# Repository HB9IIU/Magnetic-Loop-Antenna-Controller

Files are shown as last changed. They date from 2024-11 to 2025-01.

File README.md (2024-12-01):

# Magnetic Loop Antenna Auto-Tuner

## Introduction

I have always been fascinated by Magnetic Loop Antennas. While I’m not a fanatical radio ham (I only go on air occasionally and for short periods—I'm not really into contests but rather enjoy technical discussions, which are becoming increasingly rare), what truly captivates me is the challenge of tuning these antennas, especially due to their very high Q factor.

For those not familiar with the term, "high Q" refers to the quality of the antenna's resonance. A high-Q antenna means it has a very narrow bandwidth, which makes it more sensitive to small changes in frequency. This requires precise tuning, which is both challenging and rewarding. The higher the Q, the more critical it is to fine-tune the antenna for optimal performance.

---

## Project Overview
This project is a fully automated tuning system for a Magnetic Loop Antenna (MLA), designed to simplify and enhance the tuning experience, especially for high-Q antennas. The setup consists of a **Master** ESP32 microcontroller that serves as the main controller, paired with a **Slave** ESP32 that manages the motor controlling the antenna's tuning capacitor.
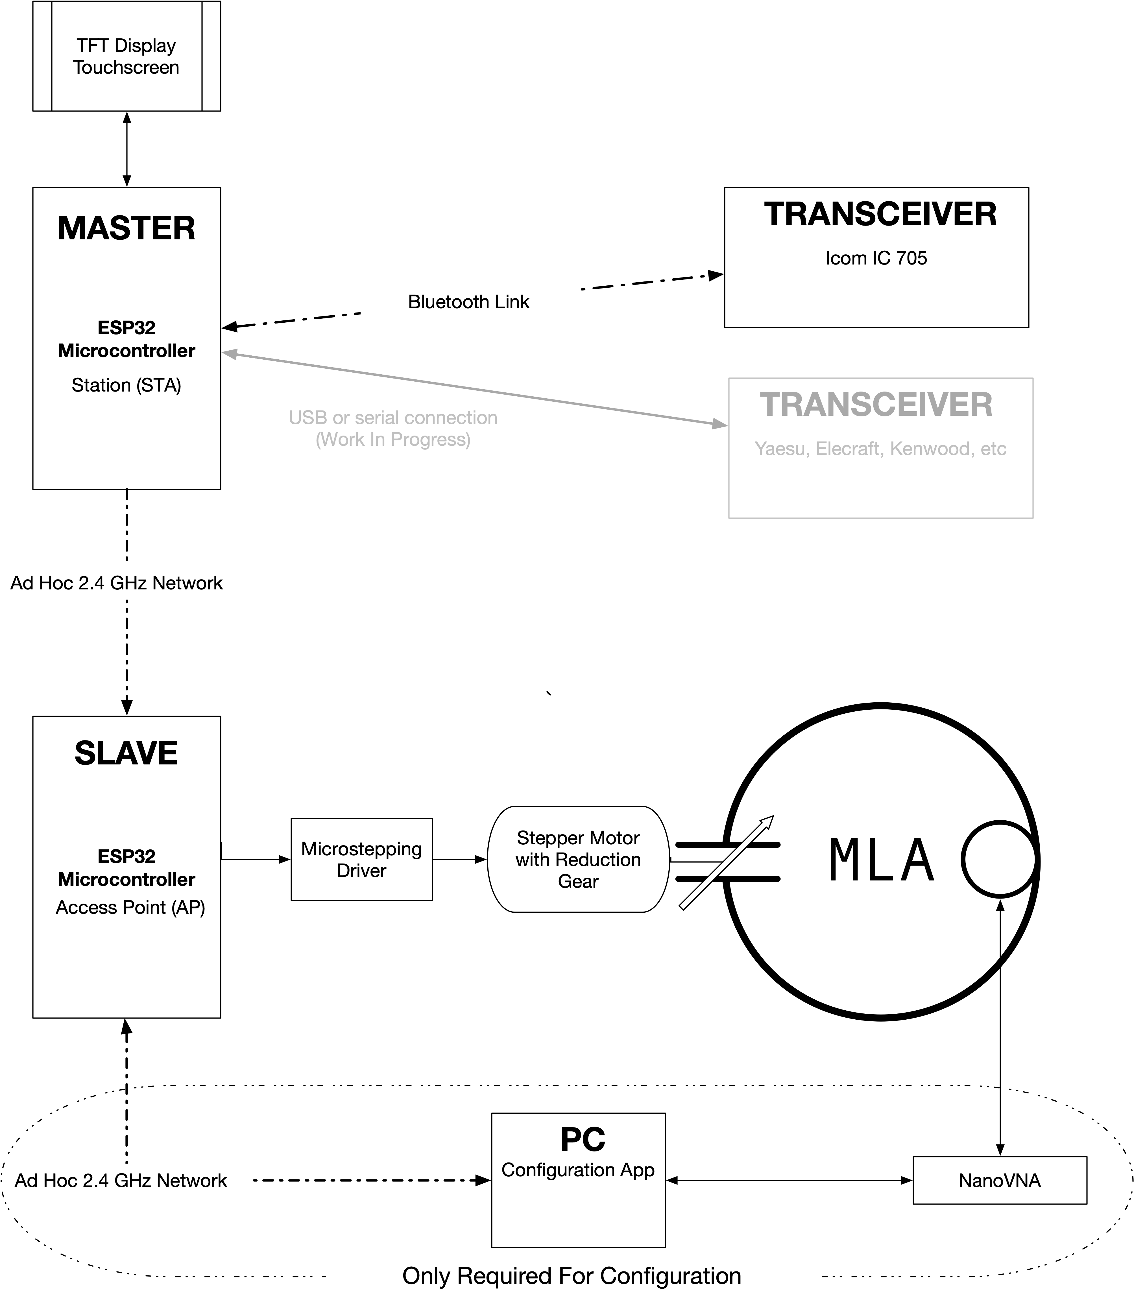
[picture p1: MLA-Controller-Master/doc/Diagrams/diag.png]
MLA Controller Image


<div style="text-align: center;">
    <a href="https://www.youtube.com/watch?v=2oa5XWuVh9o" target="_blank">
        Short Demo
    </a>
</div>

[Right-click here and open in a new tab to watch the video](https://www.youtube.com/watch?v=2oa5XWuVh9o)
<p float="left">
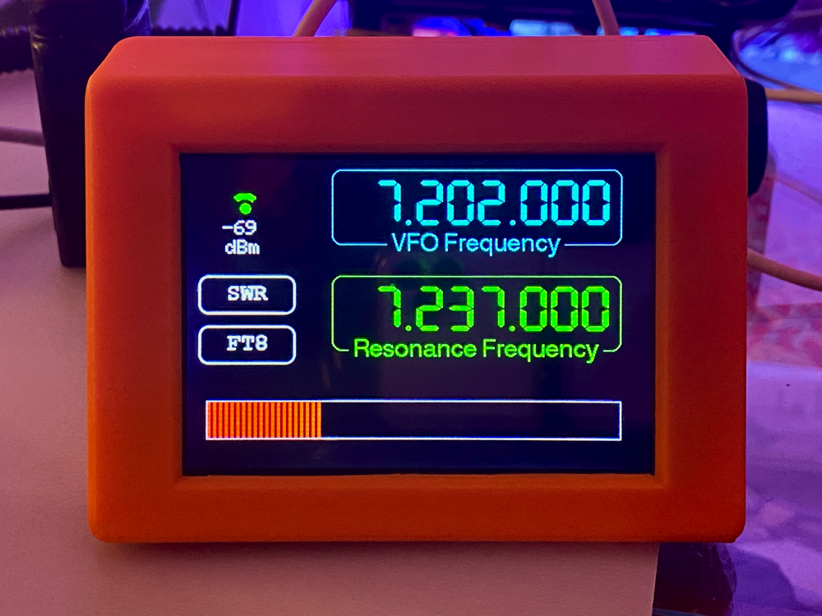
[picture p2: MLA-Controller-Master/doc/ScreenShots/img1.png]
  
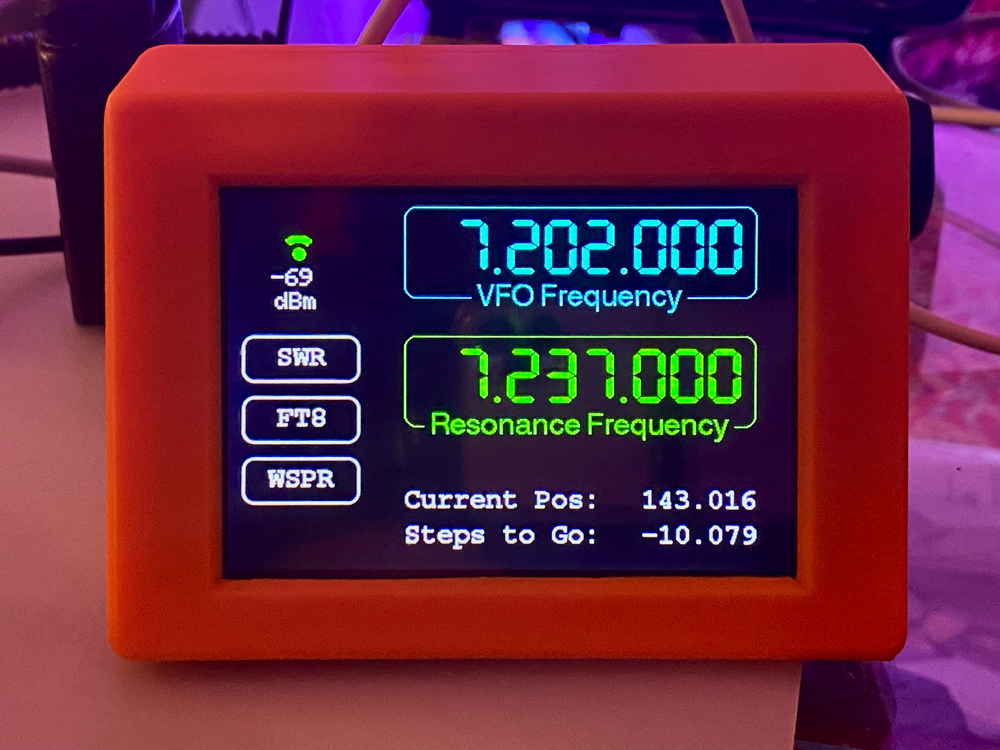
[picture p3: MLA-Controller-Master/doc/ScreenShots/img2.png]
  
</p>

### How It Works

1. **Master ESP32 with TFT Display**: 
The Master ESP32, equipped with a TFT touchscreen display, serves as the primary interface for the user. It retrieves the VFO (Variable Frequency Oscillator) frequency from an Icom IC-705 transceiver via a Bluetooth connection, allowing for automatic adjustments based on the transceiver’s operating frequency. For other transceiver models (such as Yaesu, Elecraft, Kenwood), a USB or serial connection is planned.

2. **2.4 GHz Network Communication**: The Master ESP32 communicates wirelessly with the Slave ESP32 over an ad hoc 2.4 GHz network. This approach was chosen specifically to avoid reliance on a router, making the setup ideal for field operations where access to network infrastructure may be limited.

3. **Slave ESP32 with Stepper Motor Control**: The Slave ESP32 controls a stepper motor (via a microstepping driver) connected to the MLA’s tuning capacitor. The stepper motor, equipped with a reduction gear for precision, adjusts the capacitor to achieve the desired resonance frequency based on instructions from the Master ESP32. The Slave keeps track of the capacitor position at all times, even when powered off, by storing the position data in flash memory.

4. **PC Connection for Initial Configuration**: A PC with a configuration app is required for the initial setup to generate frequency/stepper position lookup tables, which are essential for precise tuning. This calibration process, typically performed with a NanoVNA, allows the system to map resonance points accurately. Once configured, the system can operate independently without a PC, making it well-suited for portable and standalone use.

---

## Operation

When powered on, the Master Controller automatically connects to both the Slave ESP32 and the IC-705 radio. From the radio, it retrieves the current VFO frequency, and from the Slave, it gets the current capacitor position in steps, stored persistently in flash memory. This ensures that the system resumes operation quickly and accurately, even after being powered off.

After receiving the VFO frequency from the IC-705, the Master instructs the Slave to consult a lookup table (containing 5000 entries for the 20m and 40m bands, respectively). The Slave then calculates the theoretical resonance frequency and determines the number of steps needed to adjust the capacitor to match the VFO frequency. This information, including the target resonance frequency and step count, is displayed on the Master’s TFT screen, giving the user a real-time view of the tuning adjustments.

Since the TFT is a touchscreen, the user can simply tap the screen or quickly activate PTT twice on the mic to initiate the tuning process. Once tuning begins, a progress bar appears on the display, indicating that the stepper motor is in motion. This bar graph provides real-time feedback on the progress, showing the adjustment as the capacitor moves toward the target position for optimal resonance.

With another tap on the touchscreen, the user can display an SWR meter. To measure the SWR, the transceiver is briefly set to FM mode to produce a steady carrier, with the power reduced to a minimum. The system engages the PTT (Push-to-Talk) for a couple of seconds, during which the IC-705 provides SWR information via the CAT protocol—no external SWR meter is needed. This allows the user to quickly verify the antenna's tuning and get confirmation of correct tuning. No further adjustments are required. After the measurement, the transceiver is automatically returned to its initial mode and power settings.

---

## Initial Configuration

Since the system operates based on a lookup table, it’s necessary to create one initially. This could theoretically be done manually by noting down resonance frequencies for different capacitor/stepper positions. However, I wanted a fully automated solution, so I developed a Python app that controls a low-cost Chinese VNA and the Slave ESP32 to manage the stepper motor.

### Lookup Table Generation Process

1. **Positioning the Capacitor**: The capacitor is initially set to the beginning of the 20m or 40m band.
2. **Data Collection**: The VNA automatically retrieves S11 data and applies a calibration network for accurate measurements.
3. **Stepper Adjustment**: The stepper motor advances a few steps forward.
4. **Data Logging in a Loop**: Steps 2 and 3 repeat in a loop, progressively moving across the band and collecting resonance data.

The entire process and its progress are visualized on a feature-rich webpage. Once the data collection is complete, the webpage allows testing of the system’s accuracy, ensuring the lookup table is correctly aligned with actual resonance points.

After gathering all measurements, the system generates a lookup table with 5000 interpolated data points per band. This table is then uploaded to the Slave ESP32 and stored in its flash memory, providing the precise resonance positions needed for automatic tuning. Importantly, this calibration process is only required once. I completed the setup a month ago and still achieve excellent positioning accuracy. However, the calibration may need to be revisited if using an air capacitor, as climatic conditions can affect its capacitance and, consequently, the tuning stability.

---

## Additional Features

The TFT display includes a small widget that shows the quality of the 2.4 GHz link between the Master and Slave ESP32s, providing a quick visual indication of signal strength and connection stability.

Since there was extra space on the display, I also added "WSPR" and "FT8" buttons for convenience. With a simple tap, these buttons quickly tune the transceiver to the relevant frequency for WSPR or FT8, allowing the user to observe signals on the IC-705's waterfall display as a quick check of band activity.

Additionally, there’s a ‘Set’ button that brings up a virtual keyboard for frequency entry. This feature allows the user to “re-center” the lookup table if any changes have been made to the drive mechanism. By connecting a VNA, finding the resonance dip, and entering the frequency via the virtual keypad, the Slave can recalibrate and accurately identify the capacitor’s position. This ensures precise tuning and alignment with the lookup table.

---

## Open Source

If you’re interested, you can build your own system—everything is open source and available here. This is actually my first time using GitHub, so this project has also been a great opportunity to learn something new.

That said, I have limited time available, so I may not be able to provide quick fixes or improvements on the fly. I appreciate your understanding and hope you find the project useful!

---

## Final Thoughts

I have to admit, I’m extremely happy with the end result of this project. It’s amazing to see how precisely the system can tune the antenna. As a mechanical engineer, I’m familiar with the concept of backlash, but it took me a while to realize that it needed to be addressed here as well.

For those unfamiliar, "backlash" refers to the small amount of play or slippage that occurs in mechanical systems, especially when reversing direction. In a setup like mine, which uses a geared stepper motor to drive a vacuum capacitor, backlash arises not only in the reducer but also from the screw driving the capacitor. This play can introduce inaccuracies, especially when changing directions. To address this, I included a backlash compensation algorithm in the code. This ensures that the tuning remains precise regardless of direction changes, even with the mechanical slack in both the reducer and screw. The algorithm detects direction changes and adjusts the motor's movement accordingly, minimizing the effects of backlash. As a result, the system maintains high accuracy and reliable performance over time, compensating for the inherent mechanical play.

This project also helped me deepen my understanding of ESP32 coding, particularly in developing GUIs for the TFT touchscreen. Overall, I’m thrilled with how it turned out and am already looking forward to my next challenge.

If you have a project idea in mind and aren’t sure where to start, feel free to reach out—I’d be glad to help brainstorm or provide some guidance!

---
## Acknowledgments

A heartfelt thank you to the authors and contributors of the libraries used in this project. Your work has made it possible to bring this project to life. Each library brings a unique capability, and we deeply appreciate the time, effort, and expertise invested in creating and maintaining them. 🙏

## License

This project is licensed under the [MIT License](LICENSE).

## Author

**HB9IIU - Daniel**  
*Amateur Radio Enthusiast & Developer*  
Contact: daniel at hb9iiu.com

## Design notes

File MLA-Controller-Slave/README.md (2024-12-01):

# MLA-Controller-Slave

This repository contains the code for the **ESP32 microcontroller**, functioning as the **SLAVE** device in the Magnetic Loop Antenna (MLA) Controller system. The SLAVE is responsible for precise control of the MLA tuning capacitor using a stepper motor and gear reduction system.

<div style="text-align: center;">
    <a href="https://www.youtube.com/watch?v=OqZV3zAZ8kQ" target="_blank">
        Short Demo
    </a>
</div>

[Right-click here and open in a new tab to watch the video](https://www.youtube.com/watch?v=OqZV3zAZ8kQ)

## Overview

The SLAVE device communicates wirelessly with the MASTER ESP32 over an ad hoc 2.4 GHz network. It receives tuning instructions from the MASTER, calculates the required stepper motor adjustments, and ensures the tuning capacitor is positioned accurately to achieve optimal resonance.

## Key Features

- **Stepper Motor Control**: Operates a stepper motor with gear reduction for fine control of the tuning capacitor.
- **Wireless Communication**: Communicates with the MASTER ESP32 via a 2.4 GHz network for seamless coordination.
- **Persistent Position Tracking**: Maintains the capacitor's position in flash memory to ensure accuracy even after power loss.
- **Precise Resonance Tuning**: Works in tandem with the MASTER to achieve and maintain precise resonance for high-Q antennas.

## Stepper Motor Configuration and Resolution

The **DM542 stepper motor driver** is configured with a **microstep resolution of 64 microsteps per step**, achieved by setting **SW6 = OFF** and **SW7 = OFF**. With a standard 1.8° stepper motor, this results in:

```
Steps per Revolution = Microsteps per Step × Steps per Revolution (1.8° motor)
                     = 64 × 200
                     = 12,800 steps/revolution
```

The stepper motor is paired with a **1:10 gear reduction**, which multiplies the precision of the motor. The combination of microstepping and gear reduction results in a **final resolution** of:

```
Final Resolution = Steps per Revolution × Gear Ratio
                 = 12,800 × 10
                 = 128,000 steps/revolution
```

### Example: Moving from 7 MHz to 14 MHz

In practical terms, moving the tuning capacitor from **7 MHz to 14 MHz** requires approximately **1,000,000 steps**, which translates to:

```
Number of Turns = Total Steps ÷ Final Resolution
                = 1,000,000 ÷ 128,000
                ≈ 7.81 turns
```

---

## Stepper Motor Driver Connections

The SLAVE uses the DM542 stepper motor driver (or compatible) to control the stepper motor. Below are the pin connections:

- **Pulse Pin (PUL)**:
  - ESP32 Pin: `23`
  - DM542 Terminal: `PUL+` (Pulse signal input)
  - Function: Sends step signals to the driver, causing the motor to move one step per pulse.

- **Direction Pin (DIR)**:
  - ESP32 Pin: `22`
  - DM542 Terminal: `DIR+` (Direction signal input)
  - Function: Sets the motor's rotation direction (clockwise or counterclockwise).

- **Enable Pin (EN)**:
  - ESP32 Pin: `21`
  - DM542 Terminal: `EN+` (Enable signal input)
  - Function: Enables or disables the motor driver. A `LOW` signal enables the driver.

### Wiring Notes

- **Ground Connections**:
  - Connect the ESP32's `GND` to the `GND` of the DM542 (`PUL-`, `DIR-`, and `EN-` are typically connected to the driver's ground).

- **Power Supply**:
  - Ensure the DM542 is powered with an appropriate voltage for the stepper motor (typically 20-50VDC). The motor's voltage does not come from the ESP32.

### Alternative Driver

The **DM542** was chosen because it was available in my collection of spare parts, but a simpler and more compact driver, such as the **DRV8825**, could also perform this task adequately. The DRV8825 offers lower cost and size advantages, but the DM542 provides superior handling of noise, smoother operation, and higher torque at higher speeds.

---

## Important Notes

- **Included Libraries**: All required libraries are already included in the `lib` folder. There is no need to install additional libraries.
- **Recommended IDE**: This code is designed to be compiled using [PlatformIO](https://platformio.org/) in Visual Studio Code. PlatformIO offers an efficient and streamlined environment for ESP32 development.

## Documentation

For more information about the system's functionality, initial setup, and additional features, please refer to the [main repository README](https://github.com/HB9IIU/Magnetic-Loop-Antenna-Controller/tree/main).

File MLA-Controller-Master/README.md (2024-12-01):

# MLA-Controller-Master

This repository contains the code for the **ESP32 microcontroller** functioning as the **MASTER** device in the Magnetic Loop Antenna (MLA) Controller system. The MASTER is equipped with a TFT touchscreen interface, providing users with a graphical interface to control and monitor the system's operations.
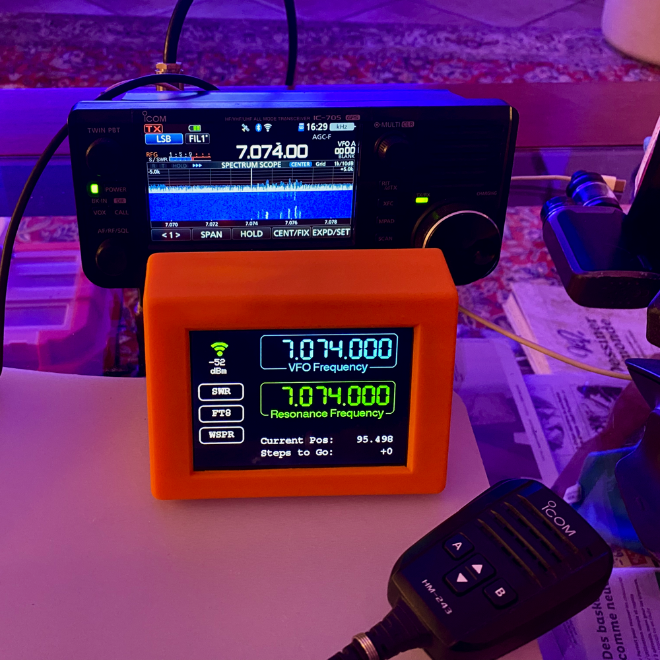
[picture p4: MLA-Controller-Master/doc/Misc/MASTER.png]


## Overview

The MASTER device retrieves the VFO (Variable Frequency Oscillator) frequency from a compatible transceiver (e.g., IC-705 via Bluetooth) and communicates wirelessly with the SLAVE ESP32 device to adjust the tuning capacitor. The graphical interface simplifies interaction, allowing precise control and real-time feedback during operation.

## Key Features

- **TFT Touchscreen**: Provides an intuitive user interface for controlling and monitoring the system.
- **Wireless Communication**: Communicates with the SLAVE ESP32 over an ad hoc 2.4 GHz network for field portability.
- **Seamless Tuning**: Automatically adjusts the MLA tuning capacitor based on the VFO frequency retrieved from the transceiver.
- **Real-Time Feedback**: Displays system status, tuning progress, and SWR readings on the screen.

## Important Notes

- **Included Libraries**: All required libraries are already included in the `lib` folder. There is no need to install additional libraries.
- **Recommended IDE**: This code is designed to be compiled using [PlatformIO](https://platformio.org/) in Visual Studio Code. PlatformIO offers an efficient and streamlined environment for ESP32 development.

## Documentation

For more information about the system's functionality, initial setup, and additional features, please refer to the [main repository README](https://github.com/HB9IIU/Magnetic-Loop-Antenna-Controller/tree/main).

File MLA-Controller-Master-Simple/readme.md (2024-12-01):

# MLA-Controller-Master-Simple

This repository contains the code for the **simplified version** of the MLA-Controller-Master. It is designed for users who want an easy, plug-and-play setup without the need for soldering or complex hardware connections.
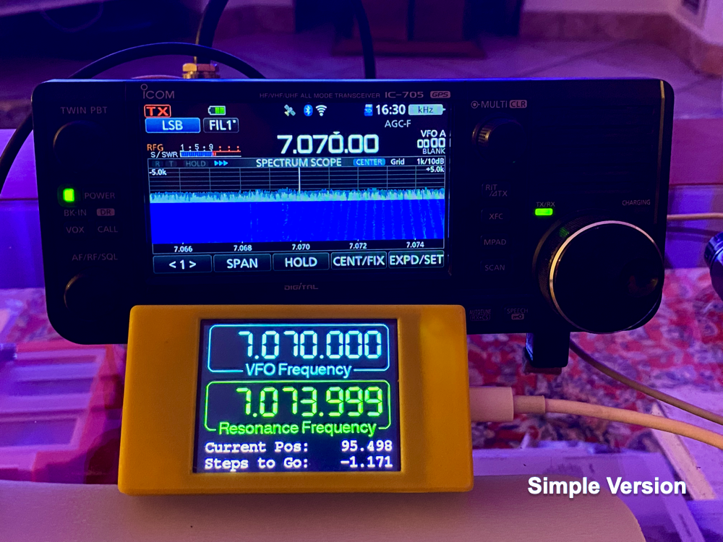
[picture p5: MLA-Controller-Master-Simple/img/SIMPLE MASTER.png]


## Key Features

- **Simplified Design**: Optimized for use with the **ESP32 Cheap Yellow Board** and its accompanying **2.2-inch 240x320 display**.
- **Core Functionality**: Provides the same essential functions as the original MASTER:
  - Retrieves frequency data from the transceiver.
  - Communicates wirelessly with the SLAVE device.
  - Controls the tuning capacitor of the Magnetic Loop Antenna.
- **No Touch Buttons**: Due to the smaller screen size, touch buttons for manual frequency selection are not included.

## Why This Version?

The **MLA-Controller-Master-Simple** was created to make the MLA system more accessible to beginners or those unfamiliar with soldering. By leveraging the **ESP32 Cheap Yellow Board**, this version eliminates the need for custom hardware connections. Users can simply flash the code and start using it.

## Hardware Requirements

- **ESP32 Cheap Yellow Board** with a **2.2-inch 240x320 display**:
  - Refer to the [ESP32-Cheap-Yellow-Display GitHub repository](https://github.com/witnessmenow/ESP32-Cheap-Yellow-Display) for more information.
- Power supply for the ESP32 and the display.
- Wireless communication setup with the SLAVE device (same as the original MASTER).

## Installation

1. **Flash the Code**:
   - Download the code from this repository.
   - Flash it onto the ESP32 Cheap Yellow Board using [PlatformIO](https://platformio.org/) or the Arduino IDE.

2. **Setup**:
   - Ensure the ESP32 Cheap Yellow Board is powered and connected to your system.
   - The display will automatically show the tuning status and frequency information.

3. **Operation**:
   - The MASTER-Simple retrieves the transceiver frequency via Bluetooth and communicates with the SLAVE to adjust the tuning capacitor.

## Differences from the Original MASTER

- **Display Size**: The original MASTER uses a **4-inch 480x320 TFT display**, whereas this version uses a smaller **2.2-inch 240x320 display**.
- **No Touch Buttons**: Frequency selection buttons are not included in this version due to the smaller screen.

## Documentation

For detailed system information and additional features, refer to the [main repository README](https://github.com/HB9IIU/Magnetic-Loop-Antenna-Controller/tree/main).

## Acknowledgments

This version leverages the excellent work from the [ESP32-Cheap-Yellow-Display repository](https://github.com/witnessmenow/ESP32-Cheap-Yellow-Display). Special thanks to the contributors for making this hardware integration seamless.

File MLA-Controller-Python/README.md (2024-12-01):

# MLA Controller Configurator

## Overview
The MLA Configurator is a Python-based application designed to automatically generate the lookup table that will be flashed to the Slave ESP32. It leverages a NanoVNA (Vector Network Analyzer) to collect measurement data across a range of frequencies.
The app uses several powerful libraries like `Flask` for server functionality, `numpy` for numerical computations, `matplotlib` for data visualization, and `scikit-learn` for data analysis and modeling. It integrates seamlessly with the NanoVNA-Q firmware and can generate calibration files and characterization data.

Check out the video for the initial configuration process of the MLA Controller:

<div style="text-align: center;">
    <a href="https://www.youtube.com/watch?v=leM8o_F7qt0" target="_blank">
        Initial Configuration
    </a>
</div>

[Right-click here and open in a new tab to watch the video](https://www.youtube.com/watch?v=leM8o_F7qt0)

## Features
- **Measurement Collection**: Interfaces with the NanoVNA and ESP32 to collect S11, SWR, and other relevant data.
- **Data Processing**: Uses advanced algorithms like cubic spline interpolation and polynomial regression to create a smooth and accurate lookup table.
- **Web Interface**: Includes a Flask server for easy configuration and interaction with the hardware.
- **Characterization and Calibration**: Supports storing and managing calibration and characterization data for future use.
- **Plotting and Visualization**: Generates plots of the antenna's performance across different frequencies, helping users visualize the characterization process.

## Development Environment
The app is developed and tested exclusively on macOS. However, it has been briefly tested on Windows, and it worked as expected. It should function similarly on both platforms, but the macOS environment is the primary development setup.

## VNA (Vector Network Analyzer)
This application works with affordable NanoVNA devices, which can be found on platforms like AliExpress under the name "NanoVNA Vector Network Analyzer." 

**For compatibility, the NanoVNA **must** be flashed with the NanoVNA-Q firmware**. No worries—there is no risk of damaging the device during the flashing process. You can find the firmware at the [NanoVNA-Q GitHub repository](https://github.com/qrp73/NanoVNA-Q), and a copy is included in this repository.

## Calibration
For first-time use, it is necessary to generate SOL calibration networks. You can do this by uncommenting the relevant lines in the code. Look for the section marked `# Uncomment to regenerate a calibration kit` and follow the instructions in the code.

## Usage
To begin the characterization process, it is recommended to set up a virtual environment for managing dependencies. Here's how you can do that:

1. **Create a virtual environment**:
   ```bash
   python3 -m venv venv
   ```

2. **Activate the virtual environment**:
   - On macOS/Linux:
     ```bash
     source venv/bin/activate
     ```
   - On Windows:
     ```bash
     .\venv\Scripts\activate
     ```

3. **Install the required dependencies**:
   ```bash
   pip install -r requirements.txt
   ```

4. **Run the Python script** to start the characterization process:
   ```bash
   python3 MLA_Configurator.py
   ```

For an optimal development experience, it is recommended to use an IDE like **PyCharm**. PyCharm provides great support for Python projects and virtual environments, making it easier to manage dependencies and work with the code.

## Dependencies
- `Flask`
- `numpy`
- `matplotlib`
- `scikit-learn`
- `skrf` (for handling network analyzer data)
- Other libraries as specified in the `requirements.txt` file.

## License
This project is licensed under the MIT License - see the [LICENSE](LICENSE) file for details.

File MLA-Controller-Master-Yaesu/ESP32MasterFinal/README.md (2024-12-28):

https://wiki.seeedstudio.com/RS-232_To_TTL_Conveter-MAX3232IDR/

# MLA-Controller-Slave

This repository contains the code for the **ESP32 microcontroller** functioning as the **MASTER** device in a radio control system. 
The MASTER is equipped with a TFT touchscreen interface, providing users with a graphical interface to control and monitor the system's operations.

## Overview

The MASTER device communicates with a SLAVE ESP32 microcontroller, which manages a stepper motor via a microstepping driver. 
This setup enables precise control of mechanical movements in various applications, such as antenna positioning for radio transceivers.
MLA Controller Image
## Features

- **TFT Touchscreen Interface**: Interactive GUI for user input and feedback.
- **Bluetooth Communication**: Connects with transceivers like the Icom IC 705.
- **Ad Hoc 2.4 GHz Network**: Facilitates wireless communication between MASTER and SLAVE devices.
- **Stepper Motor Control**: Implements microstepping for smooth and precise movements.

## Requirements

- ESP32 Microcontroller
- TFT Touchscreen Display
- Microstepping Driver
- Stepper Motor with Reduction Gear
- Required Libraries:
  - [TFT_eSPI](https://github.com/Bodmer/TFT_eSPI)
  - [WiFi](https://github.com/espressif/arduino-esp32/tree/master/libraries/WiFi)

## Installation

1. Clone the repository:
   ```bash
   git clone https://github.com/yourusername/your-repo-name.git

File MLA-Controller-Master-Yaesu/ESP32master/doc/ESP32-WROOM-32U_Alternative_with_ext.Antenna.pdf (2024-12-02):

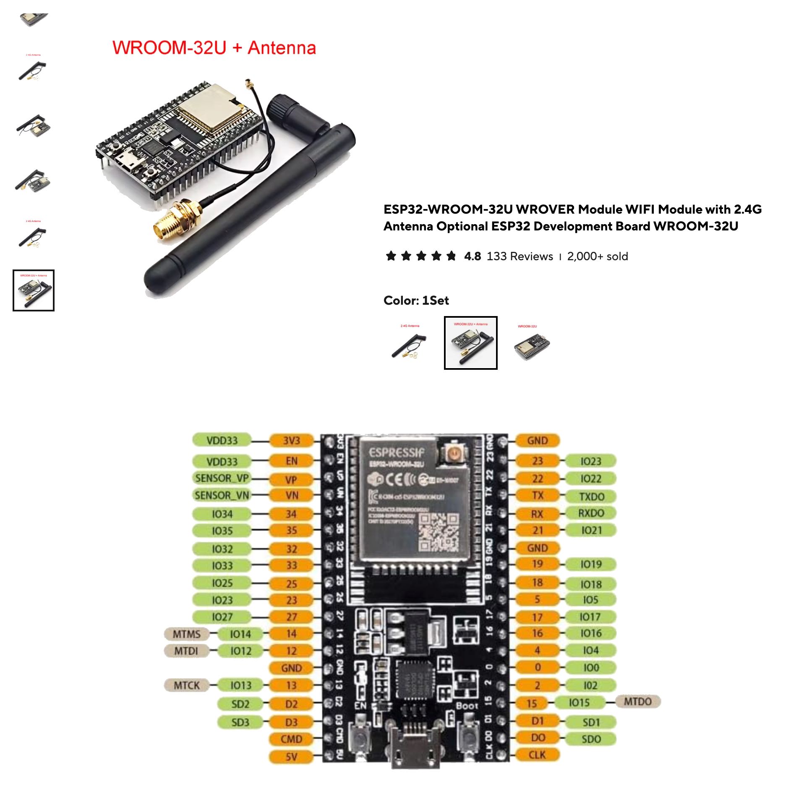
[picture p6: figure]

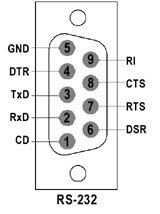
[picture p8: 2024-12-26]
MLA-Controller-Master-Yaesu/ESP32master/doc/DB9M_232Pinout.jpg

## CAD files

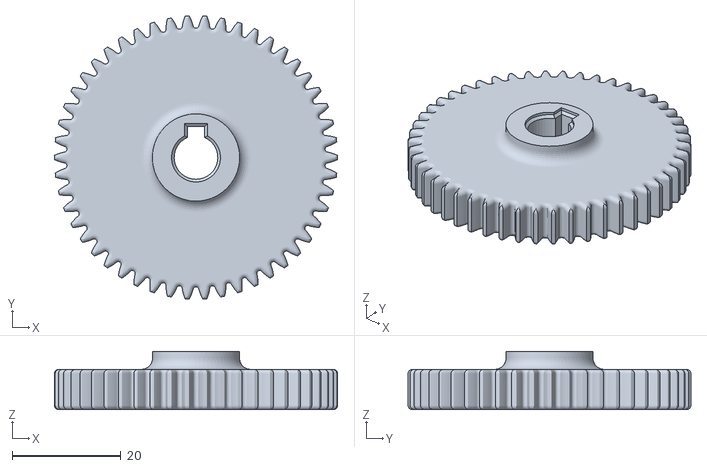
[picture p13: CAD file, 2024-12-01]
CapacitorDriveUnit/Pignion1.stl
52.0 x 51.9 x 10.7

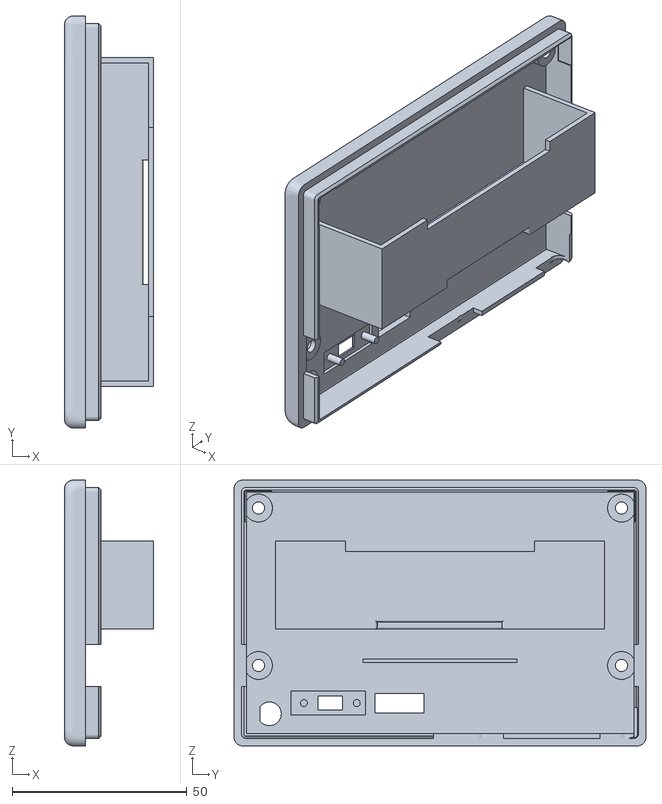
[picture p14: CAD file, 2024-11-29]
MLA-Controller-Master-Yaesu/ESP32master/doc/Enclosure3DprintFiles/STLFilesESPwithAntenna/REAR.stl
25.5 x 117.8 x 76.0

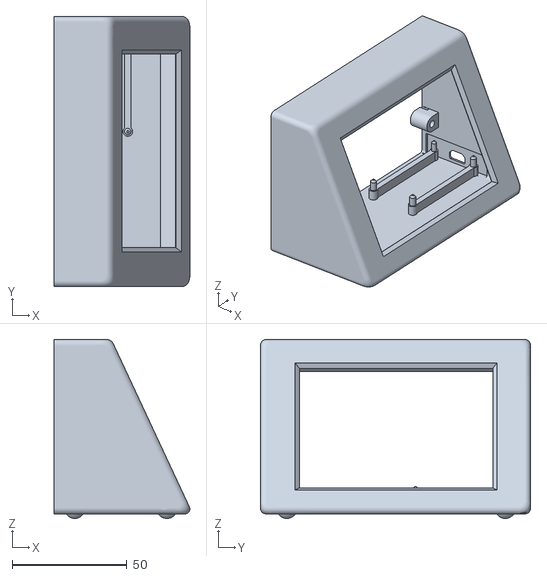
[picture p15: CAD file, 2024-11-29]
MLA-Controller-Master-Yaesu/ESP32master/doc/Enclosure3DprintFiles/STLFilesStandardESP/FRONT.stl
59.2 x 117.8 x 78.0

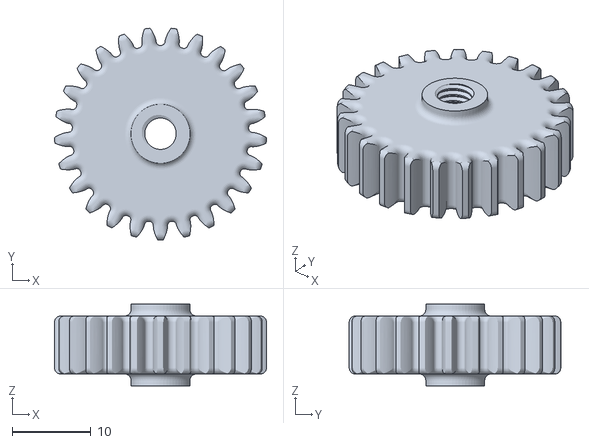
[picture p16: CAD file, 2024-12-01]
CapacitorDriveUnit/Pignion2.stl
27.0 x 26.9 x 10.4

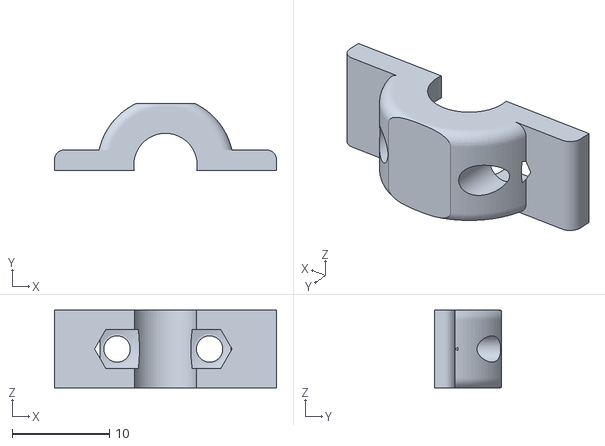
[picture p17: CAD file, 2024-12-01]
CapacitorDriveUnit/LimitSwitchCouterFlange.stl
22.8 x 6.85 x 8.00

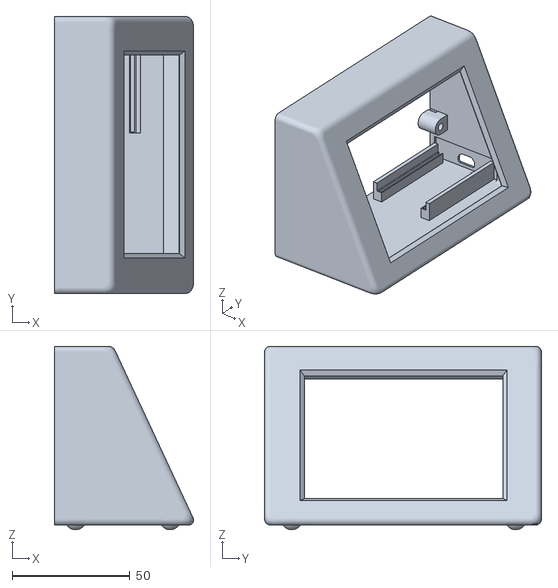
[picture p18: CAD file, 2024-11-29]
MLA-Controller-Master-Yaesu/ESP32master/doc/Enclosure3DprintFiles/STLFilesESPwithAntenna/FRONT.stl
59.2 x 117.8 x 78.0

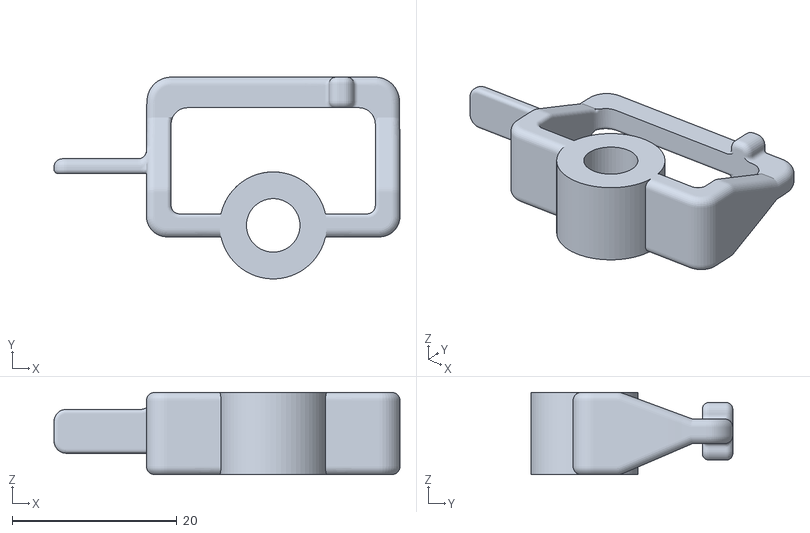
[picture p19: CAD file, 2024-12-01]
CapacitorDriveUnit/Flag.stl
42.0 x 24.5 x 10.0

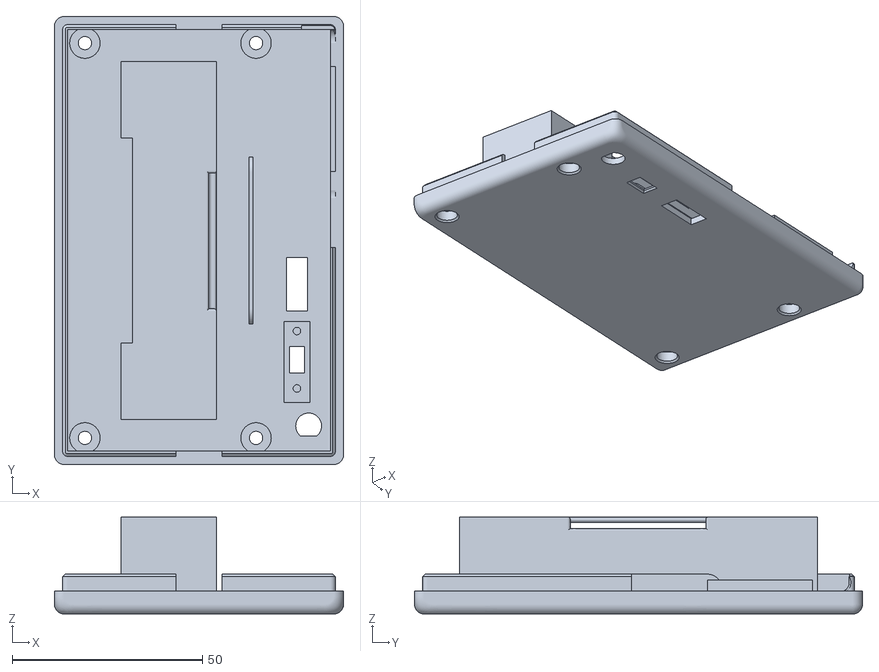
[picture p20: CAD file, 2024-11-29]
MLA-Controller-Master-Yaesu/ESP32master/doc/Enclosure3DprintFiles/STLFilesESPwithAntenna/REARwithAntenna.stl
76.0 x 117.8 x 25.5

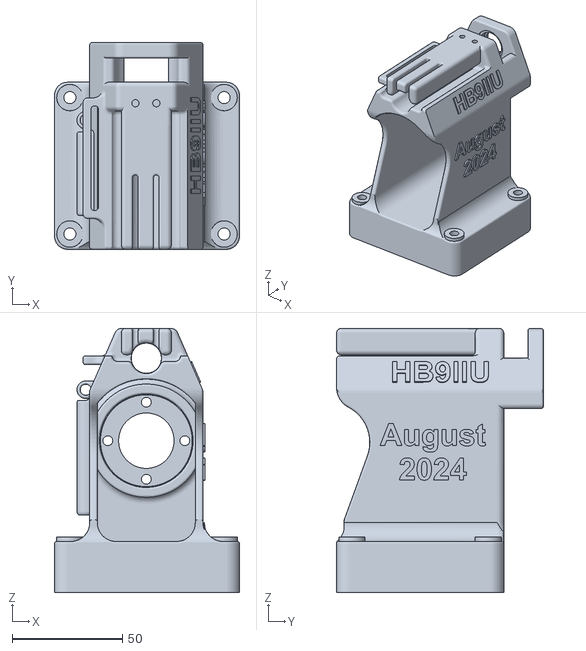
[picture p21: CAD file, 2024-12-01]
CapacitorDriveUnit/body.stl
84.1 x 94.0 x 120.0

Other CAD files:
MLA-Controller-Master-Yaesu/ESP32master/doc/Enclosure3DprintFiles/STLFilesESPwithAntenna/REAR (noantenna).stl
MLA-Controller-Master-Yaesu/ESP32master/doc/Enclosure3DprintFiles/STLFilesStandardESP/REAR.stl

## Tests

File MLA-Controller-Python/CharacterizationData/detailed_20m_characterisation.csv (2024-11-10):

Stepper Position | Characterisation Frequency
969631 | 13988656
972347 | 14016746
975063 | 14040788
977779 | 14069120
980495 | 14096882
983211 | 14124651
985927 | 14150972
988643 | 14176783
991359 | 14206248
994075 | 14232488
996791 | 14258412
999507 | 14289152
1002223 | 14315998
1004939 | 14332572
1007655 | 14363216
1010371 | 14397033
1009013 | 14382867
1006297 | 14357664
1003581 | 14326476
1000865 | 14304240
998149 | 14277112
995433 | 14246372
992717 | 14217682
990001 | 14187536
987285 | 14160351
984569 | 14132122
981853 | 14107394
979137 | 14077607
976421 | 14051555
973705 | 14025489
970989 | 13999423

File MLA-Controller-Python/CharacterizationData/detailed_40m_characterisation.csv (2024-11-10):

Stepper Position | Characterisation Frequency
51769 | 6990818
58793 | 7013480
65817 | 7036496
72841 | 7061288
79865 | 7085024
86889 | 7109096
93913 | 7131764
100937 | 7155140
107961 | 7178510
114985 | 7202246
122009 | 7228802
129033 | 7253594
136057 | 7276964
143081 | 7302254
150105 | 7324778
157129 | 7350264
153617 | 7339566
146593 | 7314050
139569 | 7289018
132545 | 7264580
125521 | 7240142
118497 | 7213916
111473 | 7189856
104449 | 7165772
97425 | 7141316
90401 | 7119026
83377 | 7095632
76353 | 7072982
69329 | 7049588
62305 | 7025528
55281 | 7000509

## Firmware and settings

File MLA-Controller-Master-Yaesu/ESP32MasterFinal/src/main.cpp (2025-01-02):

#include <myConfig.h>
#include <Arduino.h>
#include "BLEDevice.h"
#include "bluetoothManagement.h"
#include "FS.h"
#include <TFT_eSPI.h>
#include <ArduinoJson.h>
#include <HTTPClient.h>
#include "Digital_7Mono40pt7b.h"
#include "arial10pt7b.h"
#include "technology_bold18pt7b.h"

int xRectangle; // TO BE REPLACED LATER WITH NUMBERS
int wRectangle; // TO BE REPLACED LATER WITH NUMBERS
// Display Related
TFT_eSPI tft = TFT_eSPI();
#define TFT_CALIBRATION_FILE "/calibration.dat"
// WIFI RElated
#include <WiFi.h>
#define SSID "HB9IIU-MLA"          // WiFi SSID to connect to
IPAddress slaveIP(192, 168, 4, 1); // IP address of the SLAVE device to send HTTP commands to
HTTPClient http;
//------------------------------------------------------------------------------
// String currentModeName; // Will store the current mode value
// volatile uint8_t setRFPower;
// volatile unsigned long CurrentVFOFrequency = 0; // VFO frequency in Hz
volatile unsigned long previousVFOFrequency;
// volatile float currentSWR;
// volatile bool PTTstatus = false;

uint32_t currentStepperPosition = 0;       // current stepper position
int64_t theoreticalResonanceFrequency = 0; // theoretical resonance
uint32_t predictedStepperPosition = 0;     // predicted stepper position from lookup table
uint32_t deltaSteps = 0;                   // diff between current stepper position and predicted stepper position

unsigned long lastVFOfrequencyChangeTime;
bool allStepperInfotoBeRedrawn = false;
bool forceRedwrawOutofRangeWarning = true;
bool SWRtest = false;
// long estimated_movement_duration_in_microseconds;

// MILLIS related
// unsigned long lastVFOfrequencyChangeTime;
//------------------------------------------------------------------------------
// Prototype Declarations
String getModeCodeFromName(const String &modeName);
// Wifi Related
void establishWIFIconnectionWithSlave();
void getWIFIinkQuality(int8_t rssi, String &description, uint16_t &color);
// TFT display related
void initTFTscreen();
bool initializeSPIFFS();
void calibrateTFTscreen();
void checkAndApplyTFTCalibrationData(bool recalibrate);
void printOnTFT(const char *text, uint16_t textColor, uint16_t backgroundColor);
String formatStepperPosForConsoleOutput(uint32_t value);
char *formatFrequencyForConsoleOutput(uint64_t vfo);
void GetTunedStatusFromSlave();
void drawVariableCapacitor(int x, int y, float scale, uint16_t color);
String formatStepsToGoForConsole(int32_t value);
void setNewPositionForCurrentVFOfrequency(uint32_t targetFrequency);
bool VFOfrequencyIsInAdmissibleRange(unsigned long frequency);
bool redraw_swr = false;
// bool freqIsOutOfRange = false;
// bool freqBackInRange = true;
// bool allStepperInfotoBeRedrawn = false;
//--------------------------------------------------------------------------------
//  TFT Display related
void initTFTscreen()
{
    tft.init();
    pinMode(TFT_BLP, OUTPUT);
    digitalWrite(TFT_BLP, HIGH); // Turn on backlight
    tft.setRotation(1);
    tft.fillScreen(TFT_BLACK);
}

bool initializeSPIFFS()
{
    if (!SPIFFS.begin())
    {
        Serial.println("SPIFFS mount failed. Formatting SPIFFS...");
        if (SPIFFS.format())
        {
            Serial.println("SPIFFS formatted successfully. Re-initializing...");
            if (SPIFFS.begin())
            {
                Serial.println("SPIFFS mounted successfully.");
                return true;
            }
            else
            {
                Serial.println("SPIFFS re-initialization failed.");
                return false;
            }
        }
        else
        {
            Serial.println("SPIFFS formatting failed!");
            return false;
        }
    }
    Serial.println("SPIFFS mounted successfully.");
    return true;
}

void calibrateTFTscreen()
{
    uint16_t calibrationData[5];

    // Display recalibration message
    tft.fillScreen(TFT_BLACK);             // Clear screen
    tft.setTextColor(TFT_BLACK, TFT_GOLD); // Set text color (white on black)
    tft.setFreeFont(&FreeSansBold12pt7b);  // Use custom free font for better visibility
    tft.setCursor(10, 22);
    tft.fillRect(0, 0, 480, 30, TFT_GOLD);
    tft.print("   TFT TOUCHSCREEN CALIBRATION");
    tft.setTextColor(TFT_WHITE, TFT_BLACK); // Set text color (white on black)

    tft.setFreeFont(&FreeSans12pt7b); // Use custom free font for better visibility

    // Corrected and split text to display
    String line1 = "Welcome to the initial touchscreen calibration.";
    String line2 = "This procedure will only be required once.";
    String line3 = "On the next screen you will see arrows";
    String line4 = "appearing one after the other at each corner.";
    String line5 = "Just tap them until completion.";
    String line6 = "";                                    // Empty line
    String line7 = "Tap anywhere on the screen to begin"; // Final line in green

    // Variables to manage line positions
    int16_t yPos = 100; // Vertically center the text block

    // Print each line, center it horizontally
    String lines[] = {line1, line2, line3, line4, line5, line6, line7}; // Array to hold the lines
    for (int i = 0; i < 6; i++)
    { // Print lines 1-6 in white
        int16_t xPos = (tft.width() - tft.textWidth(lines[i])) / 2;
        tft.setCursor(xPos, yPos);
        tft.print(lines[i]);
        yPos += tft.fontHeight();
    }

    // Print the final line (line 7) in TFT_GREEN
    tft.setTextColor(TFT_GREEN, TFT_BLACK);
    int16_t xPos = (tft.width() - tft.textWidth(line7)) / 2;
    tft.setCursor(xPos, yPos);
    tft.print(line7);

    // Wait for touch input before continuing
    while (true)
    {
        uint16_t x, y;
        if (tft.getTouch(&x, &y))
        {
            break; // Exit the loop on touch
        }
    }
    // Erase the screen
    tft.fillScreen((TFT_BLACK)); // Fill the screen

    // Perform the calibration process
    tft.calibrateTouch(calibrationData, TFT_GREEN, TFT_BLACK, 12);

    // Store the calibration data in SPIFFS
    File f = SPIFFS.open(TFT_CALIBRATION_FILE, "w");
    if (f)
    {
        f.write((const unsigned char *)calibrationData, 14);
        f.close();
    }

    uint16_t x, y;
    int16_t lastX = -1;     // Last x position of the text
    int16_t lastY = -1;     // Last y position of the text
    String lastResult = ""; // Last printed result string

    // Draw a dynamically sized exit button
    tft.fillScreen(TFT_BLACK);
    tft.setTextColor(TFT_WHITE, TFT_BLACK);
    tft.setTextFont(4);
    String Text = "Tap anywhere to test";
    tft.setCursor((tft.width() - tft.textWidth(Text)) / 2, 8);
    tft.print(Text);

    Text = "Click Here to Exit";
    int16_t btn_w = tft.textWidth(Text) + 20;  // Dynamic button width
    int16_t btn_h = tft.fontHeight() + 12;     // Dynamic button height
    int16_t btn_x = (tft.width() - btn_w) / 2; // Center the button
    int16_t btn_y = 280;                       // Fixed vertical position
    int16_t btn_r = 10;                        // Corner radius

    tft.fillRoundRect(btn_x, btn_y, btn_w, btn_h, btn_r, TFT_BLUE);
    tft.drawRoundRect(btn_x, btn_y, btn_w, btn_h, btn_r, TFT_WHITE);
    tft.setTextColor(TFT_WHITE, TFT_BLUE);
    tft.setCursor((tft.width() - tft.textWidth(Text)) / 2, btn_y + 10);
    tft.print(Text);

    while (true)
    {

        if (tft.getTouch(&x, &y))
        {
            // Generate the new result string
            String result = "x=" + String(x) + "  " + "y=" + String(y);

            // Calculate text width and height
            int16_t textWidth = tft.textWidth(result);
            int16_t textHeight = tft.fontHeight();

            // Calculate the x and y positions to center the text
            int16_t xPos = (tft.width() - textWidth) / 2;
            int16_t yPos = (tft.height() - textHeight) / 2;

            // Set the text color to black to "erase" previous text
            tft.setTextColor(TFT_BLACK, TFT_BLACK);
            tft.setCursor(lastX, lastY);
            tft.print(lastResult); // Redraw the old result in black

            // Set the cursor to the calculated position
            tft.setCursor(xPos, yPos);

            // Print the new result
            tft.setTextColor(TFT_GREEN, TFT_BLACK); // Set text color for new text (e.g., white)
            tft.print(result);

            // Update the last printed position and result
            lastX = xPos;
            lastY = yPos;
            lastResult = result;

            // Draw a filled circle at the touch position
            tft.fillCircle(x, y, 2, TFT_RED);

            // Check if touch is within the exit button area
            if (x > btn_x && x < (btn_x + btn_w) && y > btn_y && y < (btn_y + btn_h))
            {
                Serial.println("Exit Touched");
                break;
            }
        }
    }
    tft.fillScreen(TFT_BLACK); // Clear screen
    printOnTFT("TFT display calibration applied", TFT_GREEN, TFT_BLACK);
}

void checkAndApplyTFTCalibrationData(bool recalibrate)
{

    if (recalibrate == true)
    {
        calibrateTFTscreen();
    }
    File f = SPIFFS.open(TFT_CALIBRATION_FILE, "r");
    uint16_t calibrationData[5];
    if (f && f.readBytes((char *)calibrationData, 14) == 14)
    {
        tft.setTouch(calibrationData);
        Serial.println("Calibration data applied.");
        printOnTFT("TFT display calibration applied", TFT_GREEN, TFT_BLACK);
        f.close();
    }
    else
    {
        Serial.println("Invalid calibration data. Recalibrating...");
        calibrateTFTscreen();
    }
}

void printOnTFT(const char *text, uint16_t textColor, uint16_t backgroundColor)
{
    // Static variable to keep track of the Y position across function calls
    static int currentYonTFT = 15; // Start at the top of the display

    tft.setFreeFont(&FreeMonoBold12pt7b);         // Use the bold font
    tft.setTextColor(textColor, backgroundColor); // Set text color to white, background to black

    if (currentYonTFT > 255) // adjusted manually
    {
        tft.fillScreen(TFT_BLACK); // Clear the screen with a black background
        currentYonTFT = 15;        // Reset Y position to the top of the display
    }

    int lineHeight = 24; // Adjust this value according to your font size (e.g., FreeMonoBold12pt7b)

    // Print the text at the current cursor position
    tft.setCursor(10, currentYonTFT); // Set x to 10, adjust as needed
    tft.println(text);

    // Move to the next line
    currentYonTFT += lineHeight;
}

// Wifi related
void establishWIFIconnectionWithSlave()
{
    Serial.print("Establishing WiFi Connection with Slave...");
    printOnTFT("Connecting To Slave via WiFi...", TFT_YELLOW, TFT_BLACK);

    // Attempt to connect to WiFi
    WiFi.begin(SSID);

    int attemptCounter = 0;
    String dots = "";

    while (WiFi.status() != WL_CONNECTED && attemptCounter < 15)
    {
        delay(500);
        dots += "*"; // Add a dot for each attempt
        Serial.print(".");
        attemptCounter++; // Increment the attempt counter
    }

    if (WiFi.status() == WL_CONNECTED)
    {
        int8_t rssi = WiFi.RSSI(); // Get WiFi RSSI (signal strength)
        String qualityDescription;
        uint16_t qualityColor;
        getWIFIinkQuality(rssi, qualityDescription, qualityColor);
        Serial.println("\nSuccessful Wifi Connection to Slave");
        printOnTFT("Successful Connection to Slave", TFT_GREEN, TFT_BLACK);
        Serial.print("Signal Quality:");
        Serial.println(qualityDescription.c_str());
        String message = "Link Quality: " + qualityDescription;
        printOnTFT(message.c_str(), qualityColor, TFT_BLACK);
        // Initialize HTTPClient
        String url = String("http://") + slaveIP.toString() + "/command";
        http.begin(url);
        http.addHeader("Content-Type", "application/x-www-form-urlencoded");
    }
    else
    {
        Serial.println("\nConnection failed, rebooting in 3 seconds");
        printOnTFT("No WiFi Connection to Slave", TFT_RED, TFT_BLACK);
        printOnTFT("Please check your Slave", TFT_YELLOW, TFT_BLACK);
        printOnTFT("", TFT_YELLOW, TFT_BLACK);
        printOnTFT("Re-Booting in 3 seconds", TFT_RED, TFT_BLACK);
        delay(3000);
        ESP.restart();
    }
}

void getWIFIinkQuality(int8_t rssi, String &description, uint16_t &color)
{
    if (rssi > -30)
    {
        description = "Amazing"; // Strong signal
        color = TFT_GREEN;       // Assign green color for amazing signal
    }
    else if (rssi > -67)
    {
        description = "Great"; // Good signal
        color = TFT_GREEN;     // Assign light green for great signal
    }
    else if (rssi > -70)
    {
        description = "Average"; // Fair signal
        color = TFT_YELLOW;      // Assign yellow for average signal
    }
    else if (rssi > -80)
    {
        description = "Poor"; // Weak signal
        color = TFT_ORANGE;   // Assign orange for poor signal
    }
    else if (rssi > -90)
    {
        description = "Unusable"; // Very weak signal
        color = TFT_RED;          // Assign red for unusable signal
    }
    else
    {
        description = "Unusable"; // Signal is too weak
        color = TFT_RED;          // Assign dark red for very weak signal
    }
}

//-------------------- TFT DISPLAY FUNCTION ----------------------------------------------
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
void loop()
{
    if (doConnect)
    {
        if (connectToServer())
        {
            Serial.println("Connected to server successfully.");
        }
        else
        {
            Serial.println("Connection failed. Restarting scan...");
            resetScan(5000);
        }
        doConnect = false;
    }

    // Handle reconnection if flagged
    if (reconnect && !connected)
    {
        Serial.println("Attempting to reconnect to server...");
        resetScan(5000);
        reconnect = false; // Reset flag after starting scan
    }

    // Periodically update Wifi widget
    static unsigned long lastWiFiWidgetUpdate = 0;
    if (millis() - lastWiFiWidgetUpdate > 15000)
    {
        Serial.print("Updating Wifi widget: ");
        updateWiFiWidget(53, 45, 72, 50, WiFi.RSSI(), false);
        lastWiFiWidgetUpdate = millis();
    }

    displayVFOfrequency(CurrentVFOFrequency, 121, 68, false);
    displaySetMode(currentModeName, 52, 236, TFT_WHITE, TFT_LIGHTGREY, 2, false, false);
    displaySetRFpower(setRFPower, 52, 166, TFT_WHITE, TFT_LIGHTGREY, 2, false);
    displayRXTXstatus(52, 120, PTTstatus);
    displayRESONANCEfrequency(theoreticalResonanceFrequency, 121, 176, false);

    // we use this to control the requests to the slave to not trigger while rotating the VFO knob
    if (previousVFOFrequency != CurrentVFOFrequency)
    {
        lastVFOfrequencyChangeTime = millis();
        previousVFOFrequency = CurrentVFOFrequency;
    }
    if (VFOfrequencyIsInAdmissibleRange(CurrentVFOFrequency) == false)
    {
        displayOutOfRangeWarning(140, 260);
    }

    if ((millis() - lastVFOfrequencyChangeTime) >= 300 || allStepperInfotoBeRedrawn)
    {
        if (VFOfrequencyIsInAdmissibleRange(CurrentVFOFrequency))
        {
            getStepperPositionForCurrentVFOfrequency(CurrentVFOFrequency); // Reset to prevent repetitive triggering
        }
    }

    static unsigned long previousMillisForKeypadScan = 0;
    uint16_t t_x = 9999, t_y = 9999; // To store the touch coordinate

    if (millis() - previousMillisForKeypadScan > 100)
    {
        // Detect if there’s a valid touch
        if (tft.getTouch(&t_x, &t_y))
        {
            //  Check for specific touch regions
            /*
            Serial.print("Touch detected at x");
            Serial.print(t_x);
            Serial.print(" y");
            Serial.println(t_y);
            */
            // Bottom Section
            if (isTouchPointInRegion(t_x, t_y, 145, 213, 480, 320))
            {
                Serial.print("Touch detected at bottom third");
                TuneOnClick();
            }
            // Upper Section
            if (isTouchPointInRegion(t_x, t_y, 145, 0, 480, 213))
            {
                Serial.print("Touch detected at upper third");

                SWRtest = true;

                // SWRtest = true;
            }
            // WiFi Widget
            if (isTouchPointInRegion(t_x, t_y, 0, 0, 100, 100))
            { // Bottom third of the screen
                Serial.print("Touch detected on WifiIcon");
            }
        }
        previousMillisForKeypadScan = millis();
    }
    if (SWRtest)
    {
        unsigned long SWRtestStartTime = millis();
        uint16_t SWRtestDuration = 2000;
        int RFpowerNow = setRFPower;
        String ModeNameNow = currentModeName;

        setRFpower(5);
        delay(200);
        setMode("FM");
        delay(100);
        displaySetRFpower(setRFPower, 52, 166, TFT_WHITE, TFT_LIGHTGREY, 2, false);
        setTXon();
        while (millis() < SWRtestStartTime + SWRtestDuration)
        {
            displayLogarithmicSWRMeter(currentSWR);
            // Serial.println(currentSWR);
            delay(100);
        }
        setTXoff();
        Serial.print("Setting Mode back to: ");
        Serial.println(ModeNameNow);
        setMode(ModeNameNow);
        Serial.print("Setting RF Power back to: ");
        Serial.print(RFpowerNow);
        Serial.println(" W");
        setRFpower(RFpowerNow);
        SWRtest = false;
        redraw_swr = true;
        delay(200);
        tft.fillRect(0, 228 - 5, 480, 320 - 228 + 5, TFT_BLACK);
        allStepperInfotoBeRedrawn = true;
        displayStepperInfo(150, 260, currentStepperPosition, 0, true);
        displaySetMode(currentModeName, 52, 236, TFT_WHITE, TFT_LIGHTGREY, 2, false, true);
    }
}

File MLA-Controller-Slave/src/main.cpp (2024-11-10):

#include <WiFi.h>
#include <ESPAsyncWebServer.h>
#include <Preferences.h>
#include <SPIFFS.h>


#define MAX_LOOKUP_SIZE 10000 // 2 x 5000 data sets
uint32_t lookupTable[MAX_LOOKUP_SIZE * 2];
size_t tableSize = 0;

// Driver DRV8825 at the back
#define DRM542_PUL_Pin 23 // orange
#define DRM542_DIR_Pin 22 // yellow
#define DRM542_EN_Pin 21  // green

// WiFi credentials
const char *ssid = "HB9IIU-MLA";

// Global variables (Checked)
long currentStepperPosition = 0;
long targetStepperPosition = 0;
unsigned long estimated_duration = 0;

// Global constants (Checked)
const unsigned int MIN_ACCEL_STEPS = 10000;   // Minimum steps for acceleration and deceleration
const unsigned int FINAL_DELAY = 25;         // Minimum delay for max speed
const unsigned int INITIAL_DELAY = 200;      // Maximum delay for initial speed (slow)
const long BACKLASH_CORRECTION_STEPS =22000; // Example value, adjust as needed

/////////////////////////////////////////////////////////////////////

bool debugReceivedCommands;

bool backlashCorrection = false; // Corrected variable name
int DIR = 0;                     // Direction: +1 or -1
bool moving = false;
// bool positionReached = false;   // Flag to indicate if target position is reached
unsigned long lastStepTime = 0; // To track the time between steps
float dynamicDelay = 0;         // Current delay between steps
long accelerationSteps = 0, constantSpeedSteps = 0, decelerationSteps = 0;
long stepsCompleted = 0;     // Tracks the number of steps completed
uint32_t tunedfrequency = 0; // frequency for currentStepperPosition from lookup table
uint32_t target_frequency = 0;

// Create an AsyncWebServer object on port 80
AsyncWebServer server(80);

// Create a Preferences object
Preferences preferences;

// Function prototypes
void listFilesInSPIFFS();
String formatNumberWithSeparator(long value);
uint32_t findStepperPositionFromFrequency(uint32_t frequency);
uint32_t findFrequencyFromStepperPosition(uint32_t stepperPosition);
void handleStepperMovement();
void printLookupTable(); // Function prototype for printing lookup table
char *formatVFO(uint64_t vfo);
bool loadLookupTable();
void moveStepper(unsigned long stepsToMove, int direction);
unsigned long estimateTotalMovementDuration(long targetPosition);
unsigned long estimateSinglelMovementDuration(long totalSteps);

void setup()
{
    Serial.begin(115200);
    Serial.println("\nHB9IIU MLA SLAVE Controller Started");

    // Display initial memory usage
    Serial.print("Initial Free Heap: ");
    Serial.println(formatNumberWithSeparator(ESP.getFreeHeap()));

    // For ESP32, you might also use:
    Serial.print("Max Allocatable Heap: ");
    Serial.println(formatNumberWithSeparator(ESP.getMaxAllocHeap()));

    // Initialize SPIFFS
    if (!SPIFFS.begin(true))
    {
        Serial.println("An error occurred while mounting SPIFFS");
        return;
    }
    else
    {
        Serial.println("SPIFFS mounted successfully");
        listFilesInSPIFFS();
    }

    // Display memory usage after SPIFFS mounting
    Serial.print("Free Heap after mounting SPIFFS: ");
    Serial.println(formatNumberWithSeparator(ESP.getFreeHeap()));

    // Load the lookup table
    if (!loadLookupTable())
    {
        Serial.println("Table could not be loaded");
    }
    ///printLookupTable();
    //   Display memory usage after loading the lookup table
    Serial.print("Free Heap after loading lookup table: ");
    Serial.println(formatNumberWithSeparator(ESP.getFreeHeap()));

    // Initialize preferences
    preferences.begin("HB9IIUmla", false); // 'HB9IIUmla' is the storage group name
    currentStepperPosition = preferences.getLong("currentPos", 0);

    // Display memory usage after loading preferences
    Serial.print("Free Heap after loading preferences: ");
    Serial.println(formatNumberWithSeparator(ESP.getFreeHeap()));

    Serial.print("Max Allocatable Heap: ");
    Serial.println(formatNumberWithSeparator(ESP.getMaxAllocHeap()));

    Serial.print("\nRetrieved current stepper position from non-volatile memory: ");
    Serial.print(formatNumberWithSeparator(currentStepperPosition));
    tunedfrequency = findFrequencyFromStepperPosition(currentStepperPosition);
    pinMode(DRM542_EN_Pin, OUTPUT);
    pinMode(DRM542_PUL_Pin, OUTPUT);
    pinMode(DRM542_DIR_Pin, OUTPUT);
    digitalWrite(DRM542_EN_Pin, LOW); // Enable the stepper driver
    Serial.println("\nSetting up WiFi AP...");
    WiFi.softAP(ssid);
    IPAddress local_IP(192, 168, 4, 1);
    IPAddress gateway(192, 168, 4, 1);
    IPAddress subnet(255, 255, 255, 0);
    WiFi.softAPConfig(local_IP, gateway, subnet);

    // HTTP Server endpoints
    // Add this inside your setup function
    server.on("/health", HTTP_GET, [](AsyncWebServerRequest *request)
              { request->send(200, "text/plain", "OK"); });

    server.on("/getLookupTable", HTTP_GET, [](AsyncWebServerRequest *request)
              {
                  // Default values for start and count
                  int start = 0;
                  int count = 1000;

                  // Check if "start" parameter is provided
                  if (request->hasParam("start"))
                  {
                      start = request->getParam("start")->value().toInt();
                  }

                  // Check if "count" parameter is provided
                  if (request->hasParam("count"))
                  {
                      count = request->getParam("count")->value().toInt();
                  }

                  String response = "";
                  size_t end = min(start + count, (int)tableSize);

                  for (size_t i = start; i < end; i++)
                  {
                      uint32_t frequency = lookupTable[i * 2];
                      uint32_t stepperPosition = lookupTable[i * 2 + 1];
                      response += String(frequency) + "," + String(stepperPosition) + "\n";
                  }

                  request->send(200, "text/plain", response);
                  // Serial.print("Sent data from index ");
                  // Serial.print(start);
                  // Serial.print(" to ");
                  // Serial.println(end);
              });
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

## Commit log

2024-11-29 continuous improvement
    [BACK.stl, Book1.xlsx, FRONT.stl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]
2024-12-01 Added printing Files
    [Flag.stl, LimitSwitchCouterFlange.stl, Pignion1.stl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]
2024-12-02 redraw of stepper info and wifi widget after reconnect
2024-12-03 yaesu cat
    [BACK.stl, Book1.xlsx, FRONT.stl]
2024-12-05 WORK IN PROGRESS
    [BACK.stl, Book1.xlsx, FRONT.stl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]
